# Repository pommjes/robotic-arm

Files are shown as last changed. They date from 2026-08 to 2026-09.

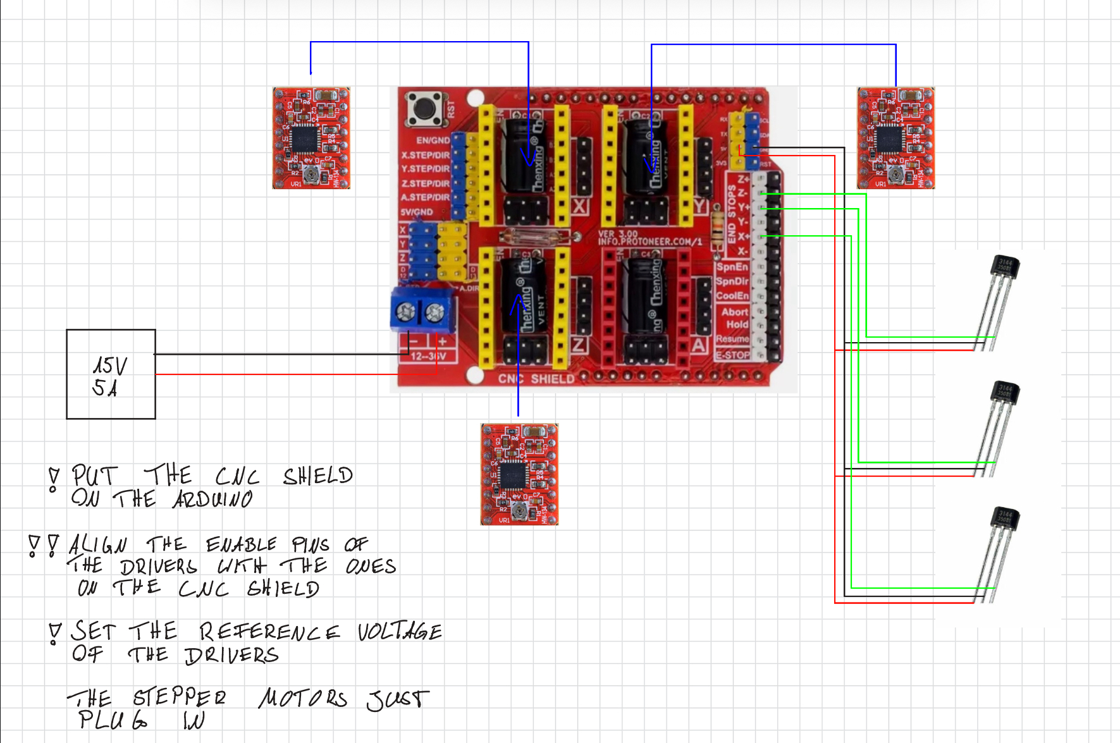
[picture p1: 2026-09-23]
assets/Wiring diagram.jpeg

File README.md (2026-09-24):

# Arduino based Robotic Arm  
> **A Hack Club Stardance project**

### Demo Link: https://youtu.be/8yHq4bUqn0A

grafik

### Hello,

This robotic arm was born out of a simple idea. I saw a video of a cycloidal drive on TikTok and decided to try building one myself — and maybe turn it into a robotic arm like the ones I saw online. 

*How hard could it be, right?*

**7 months later:** Let's just say it was *slightly* harder than expected. 

It started with a tiny 28BYJ-48 stepper motor from an Arduino starter kit. After a first weekend of designing, printing, and testing for 12 hours a day, I finished Version 1 — which, of course, was terrible.

Early Cycloidal Prototype

From there, I gradually upgraded: I bought my first NEMA stepper motors, dedicated power supply, stepper drivers, and additional hardware. The first working cycloidal drive capable of actual torque output slowly evolved into a full robotic arm. 

When I discovered **Stardance**, it gave me a massive push of motivation to finally finish this pro

### Technical specs:

- Powered by Arduino

- Controlled on your PC in Python

- 3  360° joints, two of them working with my cycloidal drive

- 320mm of total, 360° range

- Uses ~10 Watts of power during operation

- Every joint is Homable via Hall-effect sensors

- Every joint is independently controllabe down to about 0.5° steps

### Allthough I got myself a cool robotic arm on my desk now, the most important thing is what i learned.
**I Basically learned everything I know at this point from just this project:**

* CAD modelling (with 3d-printing and ease of assembly in mind)

* 3d-printing

* Soldering

* Planing and understanding circuits
  
* Design research, Parts research/logistics

Along with many more soft-skills like a general intuition of systems, designs and assemblys

##  Build & Assembly Notes
grafik

To be honest, it isn't the most intuitive design. However, the assembly view in the CAD files and the provided pictures should help you figure everything out.

* **Hardware:** Uses standard M3 screws, nuts, and washers. I recommend an assortment with multiple lengths (listed in the BOM).
* **3D Printing:** Most parts print fine in standard PLA with default settings. **Exception:** The two **"wave" components** in the cycloidal drive **must be printed with 100% infill**.
* **Assembly Tip:** The housing of Joint 2 requires force to slide onto the base due to heavy structural load — consider using a rubber mallet/hammer carefully.

grafik

>  **Circuit Warning:** This project requires working knowledge of electrical circuits and stepper motors so you don't fry your motors or drivers *(ask me how I know... :D)*.

*This is not a plug-and-play kit. It takes real assembly time and some patience to understand how everything works together. If you have questions, please leave a message in the **Discussions** tab!*

## ***Operating the arm & Software***
### Setup
1. Download the software files. You should have 3 files. 2 Python files and one C++ file.
2. Just open the Python files in you code editor and upload the C++ file to your Arduino
3. Connect the Arduino to yor PC via USB and run the Python file titled "arm_control_3.py". It should say "Succesfuly connected to Arduino

Done! You should be ready to go! The next steps:

### Zeroing the joints
Before using the "target point" app, you have to zero all of the joints as seen in the render below as horizontal as possible using the *manual joint control*.
grafik
once done, zero all the joints in the UI by pressing **Zero** (see UI below)
 
### UI & Control
* The GUI is fairly straightforward. 
* The hardware homing via Hall-sensors works, but could be modified to automatically drive to the exact zero point after triggering (varies depending on magnet/sensor placement). 
* Pay close attention to error messages in the Python terminal and the UI itself.
* Check the comments in the Python code to get a better understanding of the control software (probalby optional).
  


If anyone wants to work on it, I recommend working on the software as it is extremely rudimentary at this point only being able to perform the most basic things.

### AI usage:

**This project was done by me. AI assisted me.** This project introduced me to many new challanges like complex electric circuits, cimplicated coding (for me) as well as new physics concepts and many more.
**I used AI for some research for parts, solving hard problems and to assist my decision making process here and there**. I am sure that I would not have solved the big problems I faced if I hadnt used any AI. 
But I definitely did the work by myself and did ***not*** just do what the AI told me to do. 

(AI in this context means LLMs, i.e. Chatgpt, Gemini, Grok etc)

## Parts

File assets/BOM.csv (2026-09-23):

Item Name | Qty | Price (total) (USD) | Item link | Notes
"Standard" Nema 14 | 1 | $23.57 | https://www.omc-stepperonline.com/de/nema-14-bipolar-0-9deg-11ncm-15-58oz-in-0-4a-10v-35x35x28mm-4-draehte-14hm11-0404s | Used in joint 3
"Better" Nema 14 | 1 | $15.20 | Nema 14 Bipolar 1.8deg 40Ncm(56.64oz.in) 1.5A 35x35x52mm 4 Drähte - 14HS20-1504S|STEPPERONLINE | Used in joint 2
a4988 stepper drivers | 3 | $10.35 | https://arduino-projekte.info/products/steppertreiber-a4988 | stepper drivers
axial bearing | 1 | $7.72 | https://www.amazon.de/gp/product/B0CJ6WCP9X?smid=A3GOZYCJQ7M67E&psc=1 | used to support the rotating base
M3 screws | 1 | $8.07 | https://www.amazon.de/Schrauben-Innensechskantschrauben-Gewindeschrauben-Unterlegscheiben-Linsenkopfschrauben/dp/B0DQ3BYBLQ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 | the main type of screw in this project
exctension cables for steppers | 1 | $5.76 | https://www.amazon.de/Tiardey-Schrittmotorkabel-3D-Drucker-Schrittmotor-Schwarz/dp/B0CVVSGLK7 | Needed longer cables to ensure full freedom of arm
cnc shield | 1 | $5.66 | https://funduinoshop.com/elektronische-module/schnittstellen-konverter/cnc/a4988-cnc-shield-v3.0-fuer-arduino-uno-controller | Needed for my motors to work, soldered one myself before that which barely worked
fan for electronics | 1 | $9.10 | https://www.amazon.de/Almocn-Raspberry-L%C3%BCfter-b%C3%BCrstenloser-K%C3%BChlk%C3%B6rper/dp/B08HQ1SVFT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 | For cooling the drivers which get hot af
Nema 17 | 1 | $9.46 | https://www.omc-stepperonline.com/de/nema-17-bipolar-45ncm-63-74-oz-in-1-5a-42x42x39mm-4-draehte-17hs15-1504s-x1 | Needed for more torque for base joint
Hall effect sensors | 3 | $2.04 | https://de.aliexpress.com/item/1005007195591707.html | For homing
Magnets | 3 | $4.77 | https://www.amazon.de/dp/B0FN6WBRV8?ref=ppx_yo2ov_dt_b_fed_asin_title&th=1 | For homing
Power supply 30v 10A | 1 | owned
soldering iron + accesories | 1 | owned
bambu lab A1 printer + filament | 1 | owned
arduino | 1 | owned
multimeter | 1 | owned
tools, (lots of) cables...
Total Price (USD): | $101.70

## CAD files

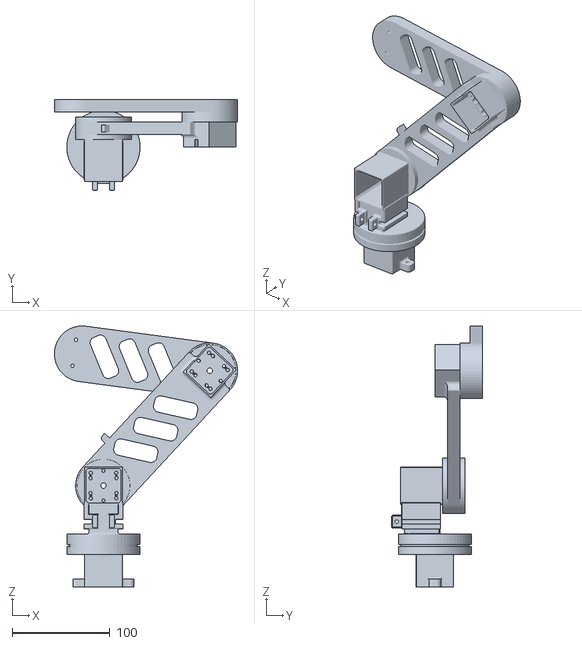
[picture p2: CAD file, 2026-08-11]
cad files/Assembly.stl
187.3 x 93.0 x 266.9

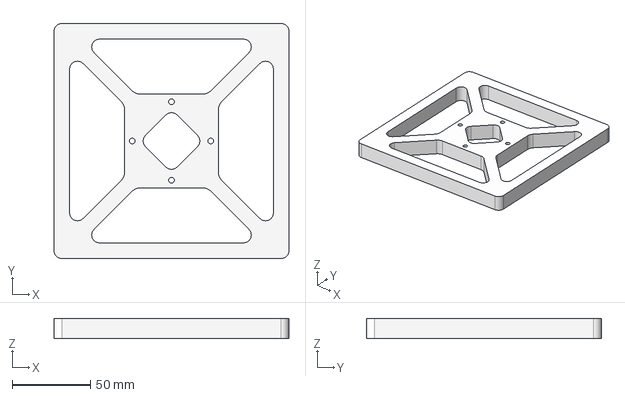
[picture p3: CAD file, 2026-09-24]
cad files/all cad files/baseplate.step
150.0 x 150.0 x 13.0 mm

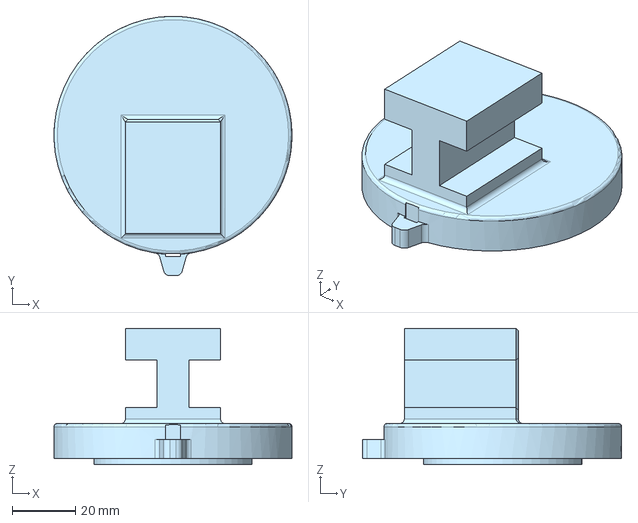
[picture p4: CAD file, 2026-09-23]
cad files/all cad files/top bearing cap.step
75.0 x 81.7 x 43.0 mm

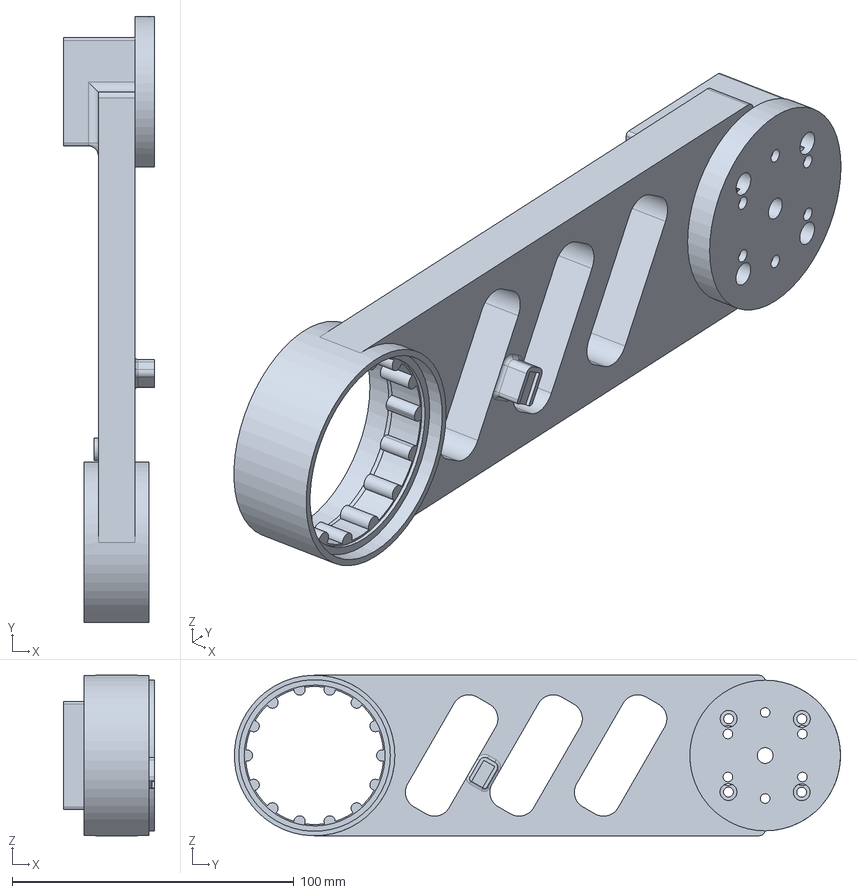
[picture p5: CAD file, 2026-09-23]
cad files/all cad files/arm 1.step
32.4 x 215.2 x 57.0 mm

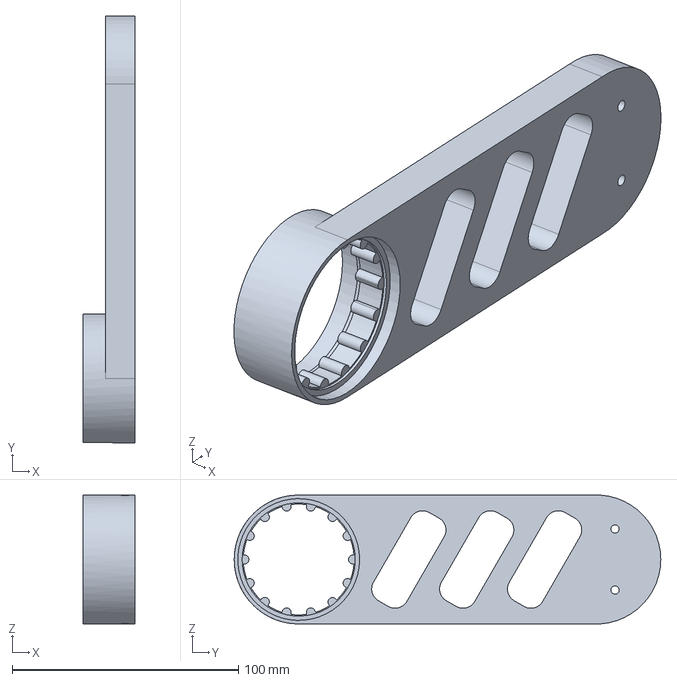
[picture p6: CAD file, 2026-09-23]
cad files/all cad files/arm 2.step
23.0 x 188.5 x 57.0 mm

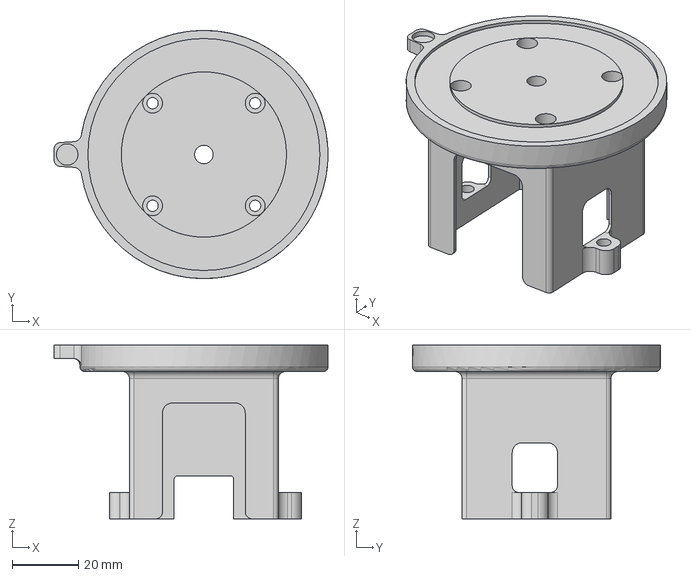
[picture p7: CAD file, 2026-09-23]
cad files/all cad files/Nema17 stepper housing.step
82.8 x 75.0 x 52.5 mm

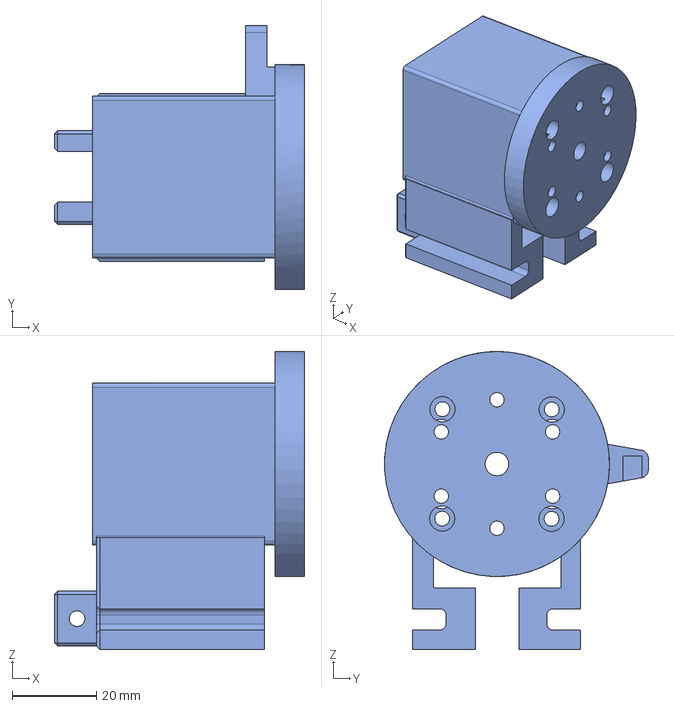
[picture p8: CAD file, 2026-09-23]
cad files/all cad files/stepper housing joint 2.step
59.5 x 62.7 x 70.8 mm

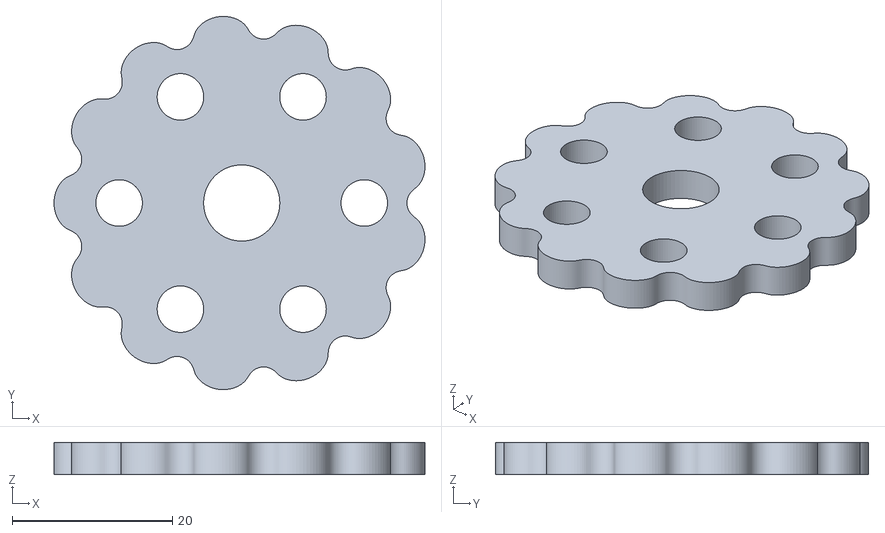
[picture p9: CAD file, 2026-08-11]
cad files/all cad files/cycloidal disc.stl
46.2 x 46.5 x 4.00

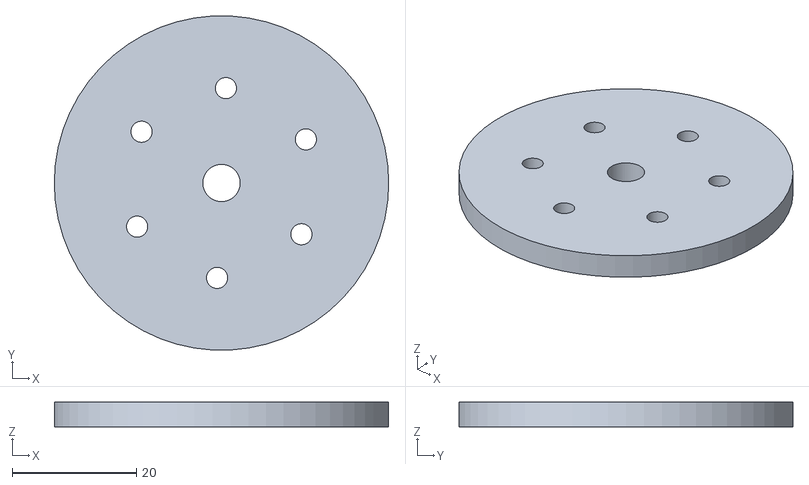
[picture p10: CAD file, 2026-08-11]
cad files/all cad files/lid.stl
53.8 x 53.7 x 4.00

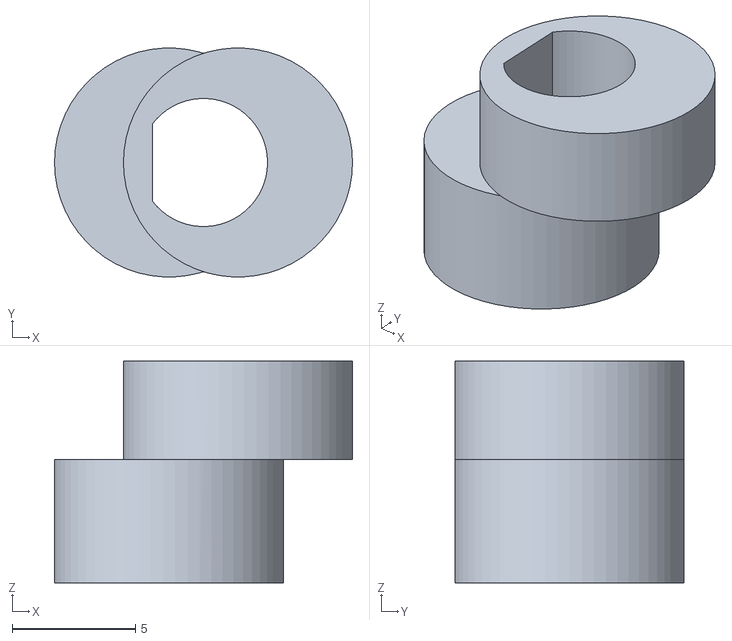
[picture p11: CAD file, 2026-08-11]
cad files/all cad files/eccentric input shaft.stl
12.1 x 9.29 x 9.00

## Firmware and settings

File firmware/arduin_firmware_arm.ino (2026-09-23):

const int stepPin_1 = 2;
const int dirPin_1  = 5;
const int spr_j1    = 3200;

const int stepPin_2 = 3;
const int dirPin_2  = 6;

const int stepPin_3 = 4;
const int dirPin_3  = 7;
const int spr_j3    = 5600;

const int SPR = 5600 ;
const int SPEED = 400;  
const int MIN_SPEED = 1200; 
const int HOME_SPEED = 600;
const int enablePin = 8;

const int x_limpin = 9;
const int y_limpin = 10;
const int z_limpin = 11;

int pos1 = 0;
int pos2 = 0;
int pos3 = 0;


int stepPins[] = {stepPin_1, stepPin_2, stepPin_3};
int dirPins[]  = {dirPin_1, dirPin_2, dirPin_3};

void setup() {
  pinMode(enablePin, OUTPUT);
  digitalWrite(enablePin, LOW);

  pinMode(stepPin_1, OUTPUT);
  pinMode(stepPin_2, OUTPUT);
  pinMode(stepPin_3, OUTPUT);
  pinMode(dirPin_1,  OUTPUT);
  pinMode(dirPin_2,  OUTPUT);
  pinMode(dirPin_3,  OUTPUT);

  pinMode(x_limpin, INPUT_PULLUP);
  pinMode(y_limpin, INPUT_PULLUP);
  pinMode(z_limpin, INPUT_PULLUP);


  Serial.begin(115200);
}

//Homing of the joints:
void homing1(){
  digitalWrite(dirPin_1, LOW);
   while (digitalRead(x_limpin) == 1){
    digitalWrite(stepPin_1, HIGH);
    delayMicroseconds(MIN_SPEED);
    digitalWrite(stepPin_1, LOW);
    delayMicroseconds(MIN_SPEED);
  }

  digitalWrite(dirPin_1, HIGH);
  for(int i = 0; i > 250; i++){
    digitalWrite(stepPin_1, HIGH);
    delayMicroseconds(MIN_SPEED);
    digitalWrite(stepPin_1, LOW);
    delayMicroseconds(MIN_SPEED);
  }

  pos1 = 0;
}

void homing2(){
  digitalWrite(dirPin_2, LOW);
   while (digitalRead(y_limpin) == 1){
    digitalWrite(stepPin_2, HIGH);
    delayMicroseconds(HOME_SPEED);
    digitalWrite(stepPin_2, LOW);
    delayMicroseconds(HOME_SPEED);
  }

  digitalWrite(dirPin_2, HIGH);
  for(int i = 0; i > 250; i++){
    digitalWrite(stepPin_2, HIGH);
    delayMicroseconds(MIN_SPEED);
    digitalWrite(stepPin_2, LOW);
    delayMicroseconds(MIN_SPEED);
  }

  pos2 = 0;
}

void homing3(){
  digitalWrite(dirPin_3, HIGH);

  while (digitalRead(z_limpin) == 1){
    digitalWrite(stepPin_3, HIGH);
    delayMicroseconds(HOME_SPEED);
    digitalWrite(stepPin_3, LOW);
    delayMicroseconds(HOME_SPEED);
  }

  digitalWrite(dirPin_3, HIGH);
  for(int i = 0; i > 250; i++){
    digitalWrite(stepPin_3, HIGH);
    delayMicroseconds(MIN_SPEED);
    digitalWrite(stepPin_3, LOW);
    delayMicroseconds(MIN_SPEED);
  }

  pos3 = 0;
}

//Moving the joints:
void moveAllJointsSimultaneous(float deg1, float deg2, float deg3) {
  float degrees[] = {deg1, -deg2, deg3};
  long sollSteps[3];

  for (int i = 0; i < 3; i++) {
    long spr = (i == 0) ? spr_j1 : ((i == 2)? spr_j3:SPR);
    sollSteps[i] = round((degrees[i] / 360.0) * spr);
    
    digitalWrite(dirPins[i], sollSteps[i] > 0 ? LOW : HIGH);
  }

  long absSteps[3] = { abs(sollSteps[0]), abs(sollSteps[1]), abs(sollSteps[2]) };

  long maxSteps = max(absSteps[0], max(absSteps[1], absSteps[2]));

  if (maxSteps == 0) return;

  long accelSteps = maxSteps * 0.20;
  long decelSteps = accelSteps;

  long counter[3] = {0, 0, 0};

  for (long i = 0; i < maxSteps; i++) {
    
    int currentDelay;
    if (i < accelSteps) {
      currentDelay = map(i, 0, accelSteps, MIN_SPEED, SPEED);
    } else if (i < maxSteps - decelSteps) {
      currentDelay = SPEED;
    } else {
      currentDelay = map(i, maxSteps - decelSteps, maxSteps, SPEED, MIN_SPEED);
    }

    for (int j = 0; j < 3; j++) {
      if (absSteps[j] > 0) {
        counter[j] += absSteps[j];
        if (counter[j] >= maxSteps) {
          digitalWrite(stepPins[j], HIGH);
        }
      }
    }

    delayMicroseconds(currentDelay);

    for (int j = 0; j < 3; j++) {
      if (absSteps[j] > 0 && counter[j] >= maxSteps) {
        digitalWrite(stepPins[j], LOW);
        counter[j] -= maxSteps; 
      }
    }

    delayMicroseconds(currentDelay);
  }
  Serial.println("OK"); 
}

//processing python inputs:
void parseMultiCommand(String input) {
  input.trim();
  input.toLowerCase();
  input.replace("°", "");

  if (input.startsWith("home:")){
    String target = input.substring(5);
    target.trim();
 
    if (target == ("1")){
      homing1();
    }
    else if (target == ("2")){
      homing2();
    }
    else if (target == ("3")){
      homing3();
    }

    Serial.println("OK");
      return;
  }

  float deg1 = 0.0, deg2 = 0.0, deg3 = 0.0;

  int firstComma = input.indexOf(',');
  int secondComma = input.indexOf(',', firstComma + 1);

  if (firstComma != -1 && secondComma != -1) {
    String str1 = input.substring(0, firstComma);
    String str2 = input.substring(firstComma + 1, secondComma);
    String str3 = input.substring(secondComma + 1);

    
    if (str1.indexOf(':') != -1) str1 = str1.substring(str1.indexOf(':') + 1);
    if (str2.indexOf(':') != -1) str2 = str2.substring(str2.indexOf(':') + 1);
    if (str3.indexOf(':') != -1) str3 = str3.substring(str3.indexOf(':') + 1);

    deg1 = str1.toFloat();
    deg2 = str2.toFloat();
    deg3 = str3.toFloat();

    moveAllJointsSimultaneous(deg1, deg2, deg3);
  }
}

void loop() {
  if (Serial.available() > 0) {
    String input = Serial.readStringUntil('\n');
    parseMultiCommand(input);
  }
}

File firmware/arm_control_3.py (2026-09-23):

import customtkinter as ctk
import math
from math import*
from arduino_connection import ArduinoController


#CTK settings and init
ctk.set_appearance_mode("dark")                 #"light"- for light mode
ctk.set_default_color_theme("green")            #"blue"- to turn Ui blue

app = ctk.CTk()
app.title("Hello CustomTkinter")
app.geometry("900x800")
app.minsize(900, 800)

#main_frame = ctk.CTkFrame(app)
#main_frame.pack(fill="both", expand=True, padx=10, pady=10)

down_panel = ctk.CTkFrame(app, height=270)
down_panel.pack(side = "bottom",fill = "x", padx=10, pady=10  )

#errors and messages for user
error_label0 = ctk.CTkLabel(down_panel, text="Messages:", font=("Helvetica", 18))
error_label0.place(x = 200, y = 150)

error_label1 = ctk.CTkLabel(down_panel, text_color = "red" ,text="", font=("Helvetica", 16))
error_label1.place(x = 320, y = 180)

error_label2 = ctk.CTkLabel(down_panel, text_color= "grey",text = "make sure to also keep an eye on the terminal for additional error messages" ,font = ("Helvetica", 14))
error_label2.place(x = 200, y=  210)

L1, L2 = 16,16

#alt = old, neu = new
pos1_alt, pos2_alt, pos3_alt = 0.0, 0.0, 0.0

def gui_logger(message: str, is_error: bool):
    color = "red" if is_error else "green"
    error_label1.configure(text=message, text_color=color)

port = 'COM5'#                                                           <---- put the usb port as the one your arduino is connected to. Also do this in "arduino.connection.py"
arduino = ArduinoController(port=(port), baudrate=115200)

if arduino.connect():
    error_label1.configure(text = "succesfuly connected to arduino!", text_color = "green")
else:
    error_label1.configure(text = "arduino not connected.", text_color = "red")

#sending all the inputs to the arduino
def send_data1():
    arduino.send_angles(delta1, delta2, delta3)

def send_data2():
    global pos1_alt,pos2_alt,pos3_alt, j1move, j2move, j3move

    arduino.send_angles(j1move, j2move, j3move)

    if j1move is not None:
            pos1_neu = round(pos1_alt + j1move, 4)
            pos1_alt = pos1_neu
    if j2move is not None:
            pos2_neu = round(pos2_alt + j2move, 4)
            pos2_alt = pos2_neu
    if j3move is not None:
            pos3_neu = round(pos3_alt + j3move, 4)
            pos3_alt = pos3_neu

def home_joint1():
    global pos1_alt
    arduino.home(joint="1", callback=lambda: reset_pos(1))

def home_joint2():
    global pos2_alt
    arduino.home(joint="2", callback=lambda: reset_pos(2))

def home_joint3():
    global pos3_alt
    arduino.home(joint="3", callback=lambda: reset_pos(3))

def home_joint_all():
    arduino.home(joint="ALL", callback=lambda: reset_pos("ALL"))

def reset_pos(joint):
    global pos1_alt, pos2_alt, pos3_alt
    if joint == 1 or joint == "ALL":
        pos1_alt = 0.0
    if joint == 2 or joint == "ALL":
        pos2_alt = 0.0
    if joint == 3 or joint == "ALL":
        pos3_alt = 0.0 


def zero_joint1():
    global pos1_alt
    pos1_alt = 0.0

def zero_joint2():
    global pos2_alt
    pos2_alt = 0.0

def zero_joint3():
    global pos3_alt
    pos3_alt = 0.0

def update_pos_display():
    pos_label.configure(text = f"Positions: \n\n Joint 1: {pos1_alt}°\n\n Joint 2: {pos2_alt}°\n\n Joint 3: {pos3_alt}°")
    app.after(200, update_pos_display)


def get_val(entry):
    try:
        return float(entry.get())
    except ValueError:
        return None

def calculate():
    global pos1_alt, pos2_alt, pos3_alt, delta1, delta2, delta3

    L1,L2 = 16,16

    int_x = get_val(xentry)
    int_y = get_val(yentry)
    int_z = get_val(zentry)

    if int_x is not None and int_y is not None and int_z is not None:
        #calculating base angle
        theta1 = atan2(int_z, int_x)

        y_2d = sqrt(int_x*int_x + int_z*int_z)
        x_2d = int_y

        #calculating value for the angle calculations
        value = (x_2d*x_2d+y_2d*y_2d-L1*L1-L2*L2)/(2*L1*L2)

        #calculating the joint angles. a and b are different models while theta 2&3 are the two different joints
        theta3_a = acos(value)
        theta2_a = atan2(y_2d,x_2d) - atan2(L2 * sin(theta3_a), L1+L2*cos(theta3_a))

        theta3_b = -acos(value)
        theta2_b = atan2(y_2d,x_2d) - atan2(L2 * sin(theta3_b), L1+L2*cos(theta3_b))

        #checking if the calculated angles are actually possible
        elbow_y_a = L1 * sin(theta2_a)
        end_y_a = (L1 * sin(theta2_a)+ L2 * sin(theta2_a + theta3_a))

        elbow_y_b = L1 * sin(theta2_b)
        end_y_b = (L1 * sin(theta2_b)+ L2 * sin(theta2_b + theta3_b))

        min_height = 0

        legal_a = elbow_y_a >= min_height and end_y_a >= min_height
        legal_b = elbow_y_b >=min_height and end_y_b >= min_height

        deg1 = round(degrees(theta1), 4)
        deg2a = round(degrees(theta2_a), 4)
        deg2b = round(degrees(theta2_b), 4)
        deg3a= round(degrees(theta3_a), 4)
        deg3b = round(degrees(theta3_b), 4)

        if legal_a:
            output_label1.configure(text = f"θA1: {deg1}° | θA2: {deg2a}° | θA3: {deg3a}°")
            pos1_neu,pos2_neu,pos3_neu = deg1, deg2a, deg3a
        elif legal_b:
            output_label1.configure(text = f"θB1: {deg1}° | θB2: {deg2b}° | θB3: {deg3b}°")
            pos1_neu,pos2_neu,pos3_neu = deg1, deg2b, deg3b
        else:
            output_label1.configure(text = f"no possible positions found")

        #calculating the angle wich would result in the new position.          ###THIS IS THE DATA NEEDED TO SEND TO ARDUINO AND CONTROLL THE JOINTS!
        delta1 = round(pos1_neu - pos1_alt, 4)
        delta2 = round(pos2_neu - pos2_alt, 4)
        delta3 = round(pos3_neu - pos3_alt, 4)

        output_label2.configure(text = f"∆1:{delta1}° | ∆2:{delta2}° | ∆3:{delta3}°")

        pos1_alt, pos2_alt, pos3_alt = pos1_neu, pos2_neu, pos3_neu

        error_label1.configure(text = "All inputs seem to be valid!", text_color = "green")
    else:
        error_label1.configure(text = "All 3 inputs must be filled out", text_color = "red")
        delta1 = None
        delta2 = None
        delta3 = None

def move():
    global pos1_alt,pos2_alt,pos3_alt, j1move, j2move, j3move

    j1move = get_val(j1entry)
    j2move = get_val(j2entry)                                                           #### THE VALUES FOR SINGLE JOINT MOVEMENTS ARE HERE
    j3move = get_val(j3entry)


    output_label3.configure(text = f"∆1: {j1move}° | ∆2: {j2move}° | ∆3: {j3move}°")
    output_label4.configure(text = "Make sure to delete unwanted commands before sending!!")

main_label = ctk.CTkLabel(app, text="UI for 3DOF robotic arm", font=("Helvetica", 23))
main_label.place(x = 340, y = 20)

pos_label = ctk.CTkLabel(app, text = "", font = ("Helvetica", 20))
pos_label.place(x = 380, y = 100)

#widgets for first function
label_1 = ctk.CTkLabel(app, text="Inputs for target point:", font=("Helvetica", 18))
label_1.place(x = 90, y= 100)
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

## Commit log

2026-08-11 Create cad models
2026-08-11 Rename Assembly.stl to Assembly(only 3dp parts).stl
    [Assembly(only 3dp parts).stl]
